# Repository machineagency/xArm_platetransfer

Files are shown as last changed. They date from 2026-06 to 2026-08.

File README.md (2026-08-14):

This is the code repo to use xArm for plate transportation between the Jubilee and a plate shelf.

code

# Setup

1. Create python 3.13 virtual environment

   ```shell
   python3.13 -m venv .venv
   source .venv/bin/activate
   ```
2. install xArm-Python-SDK

   ```shell
   git clone https://github.com/xArm-Developer/xArm-Python-SDK.git
   cd xArm-Python-SDK
   pip install .
   ```

   How to connect to xArm:

   * Turn on the power for the xArm, connect ethernet cable to laptop/Raspberry Pi.
   * It takes few seconds for the xArm to establish internet connection, after the connection box makes three beep sound, run the python code for connecting to xArm.
3. install science jubilee

   ```shell
   git clone https://github.com/machineagency/science-jubilee.git
   cd science-jubilee
   python3 -m pip install -e .
   ```
4. Attach the physical marker on the edge of the print plate.

   3D print a [plate edge marker](./hardware/3D models/plate_edge_marker.stl) and attach to the upper right corner of the print plate. This was used for locating the edge for the print plate.

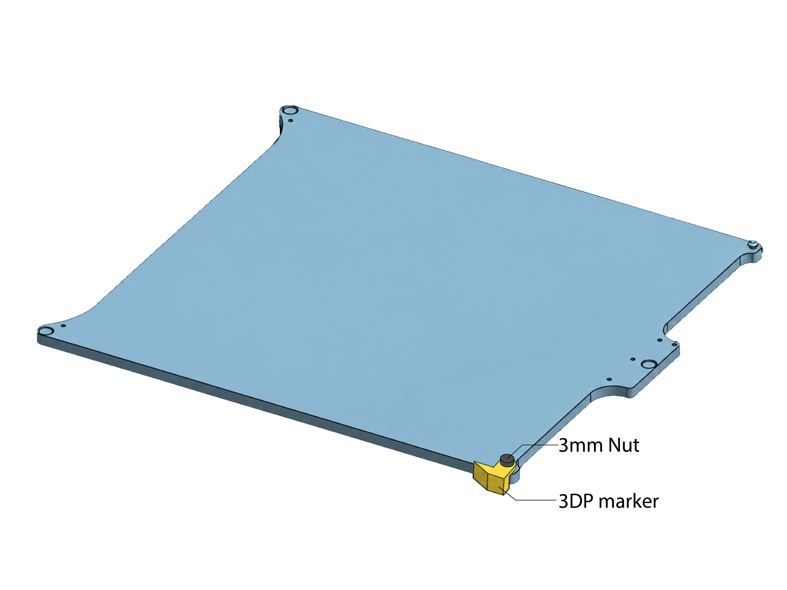
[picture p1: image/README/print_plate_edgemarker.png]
print_plate_edgemarker jig_placement_2
   

# Plate Position Calibration

1. Place the plate on the position you want to register (e.g., shelf/Jubilee), with the 3DP marker on the plate edge closer to the xArm.
2. Run the function `register_position` in `PlateHandler` class.
3. After running the code, manually perform a rough alignment of the xArm to the plate: position the side end stop at the plate’s height and approximately at the midpoint of the plate edge. The holder tool loaded on the xArm should also be approximately parrallel to the plate. Once the rough alignment is complete, press Enter. The xArm will perform automatic calibration process.

# Example Workflow

## Plate transfer & camera capture image

In the camera_workflow_gelinspection.ipynb, we showcased how to use the plate transferring capability with xArm in a webcam capturing workflow. The xArm can pickup different plates on the shelf, put into theJubilee, and use the Jubilee toolhead to pickup a camera tool to capture images of the plate. [Video demo](./video/plate_transfer_cam_workflow.mp4).

example images taken of the different plates:

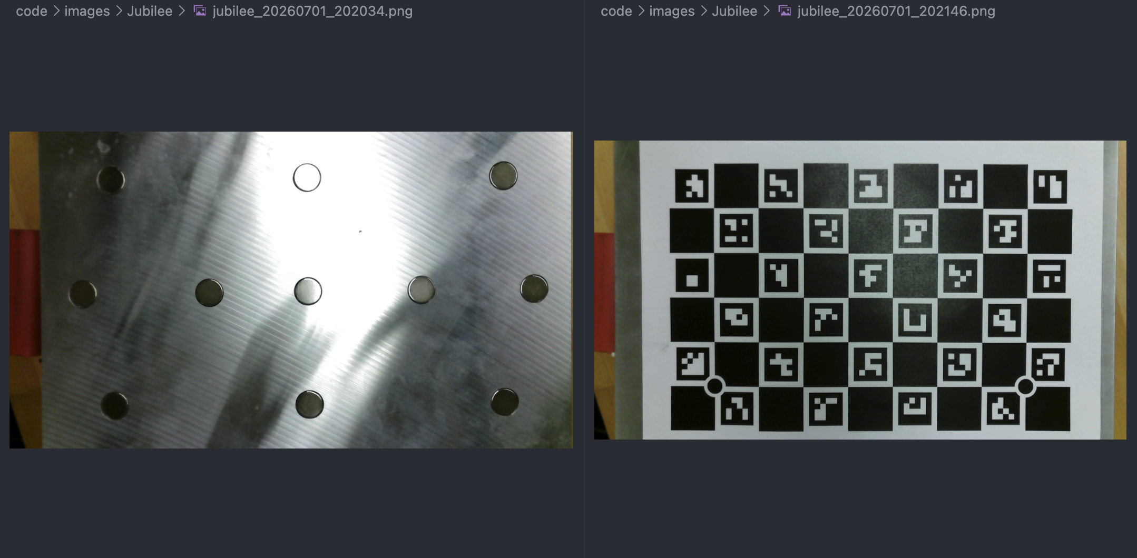
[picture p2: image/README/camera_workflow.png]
camera_workflow


This could also support multi-plate orchestration workflows, where individual plates might require long overall durations but only brief access to the Jubilee. For example, when monitoring hydrogel swelling and deswelling cycles, the Jubilee may only be needed for a few minutes at each stage to capture images or add water/solution, while the swelling or drying process itself takes several hours. During these waiting periods, the plate can be stored on the shelf and automatically loaded onto the Jubilee only when imaging, solution refilling, or other interventions are required.

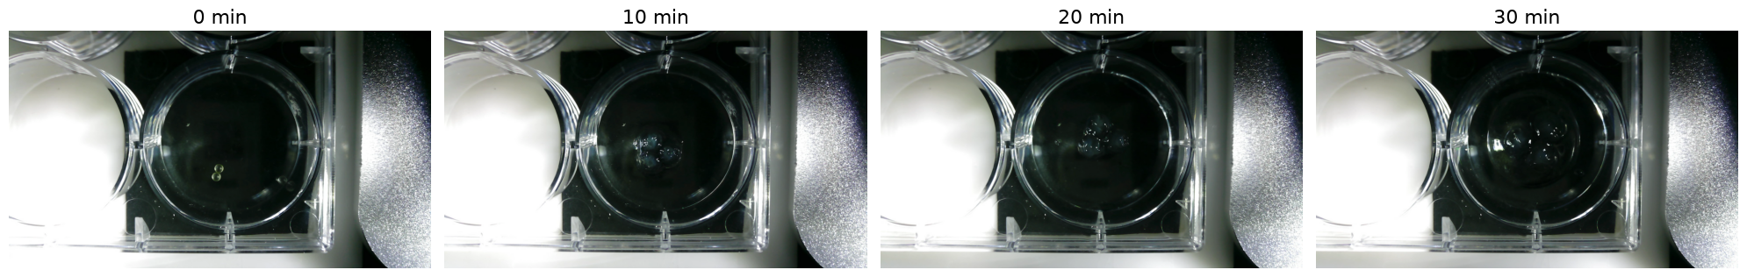
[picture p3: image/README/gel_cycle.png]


# Notes

1. After running the alignment code for the plate at the shelf and Jubilee, the position of the Jubilee and shelf cannot be changed, otherwise needs recalibration.
2. The space between the Jubilee and the shelf should be relatively large to prevent collisions. If the space is too tight, the arm may not be able to move safely or solve a valid path to certain locations.
3. In the Jubilee workflow example, the IP address of the Jubilee was changed to `192.168.2.2` to avoid conflict with xArm address (`192.168.1.205`).

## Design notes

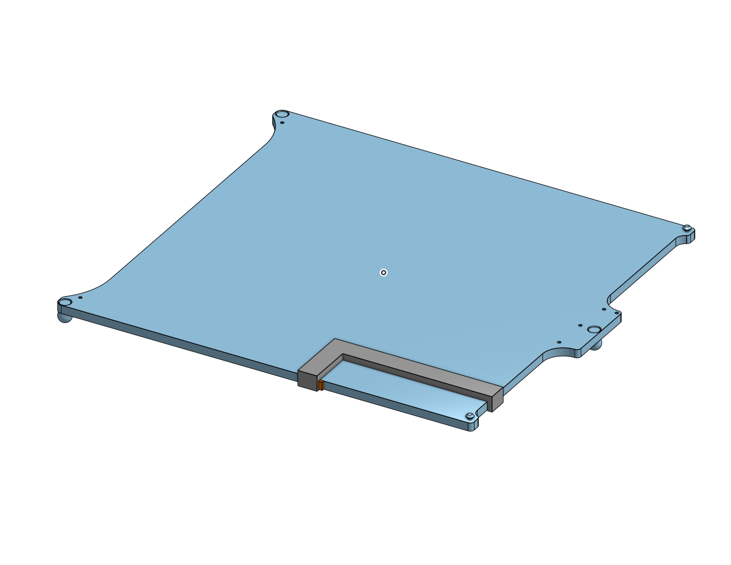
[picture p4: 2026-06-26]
image/README/jig_placement.png

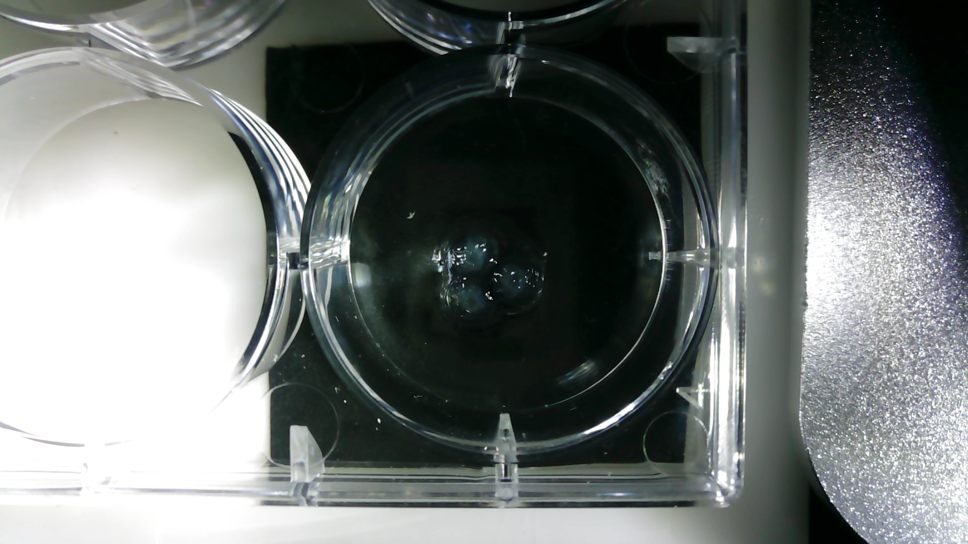
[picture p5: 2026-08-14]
code/images/Jubilee/jubilee_20260813_210422.png

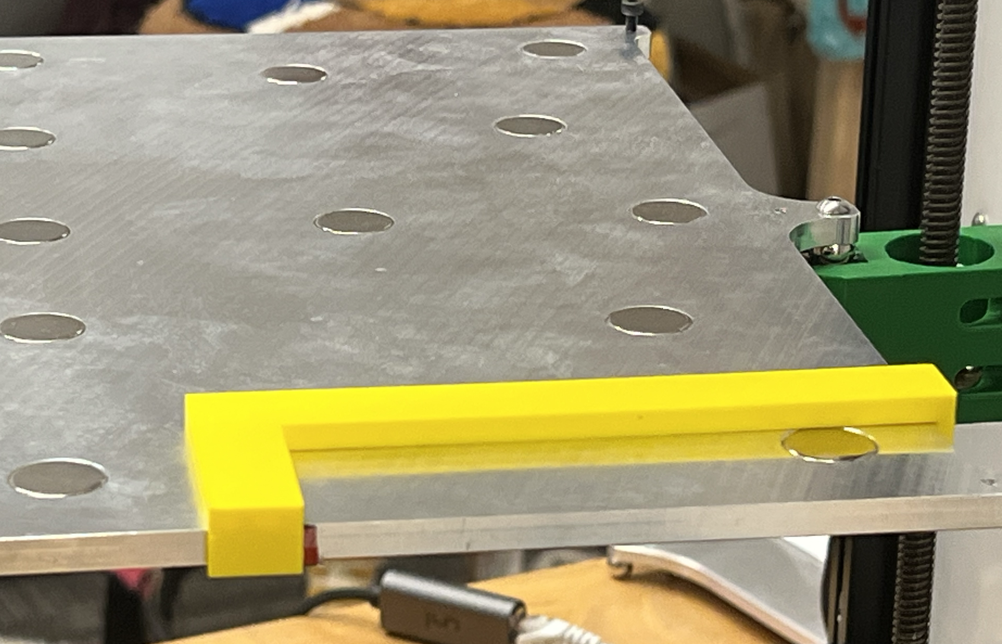
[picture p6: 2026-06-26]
image/README/jig_placement_2.png

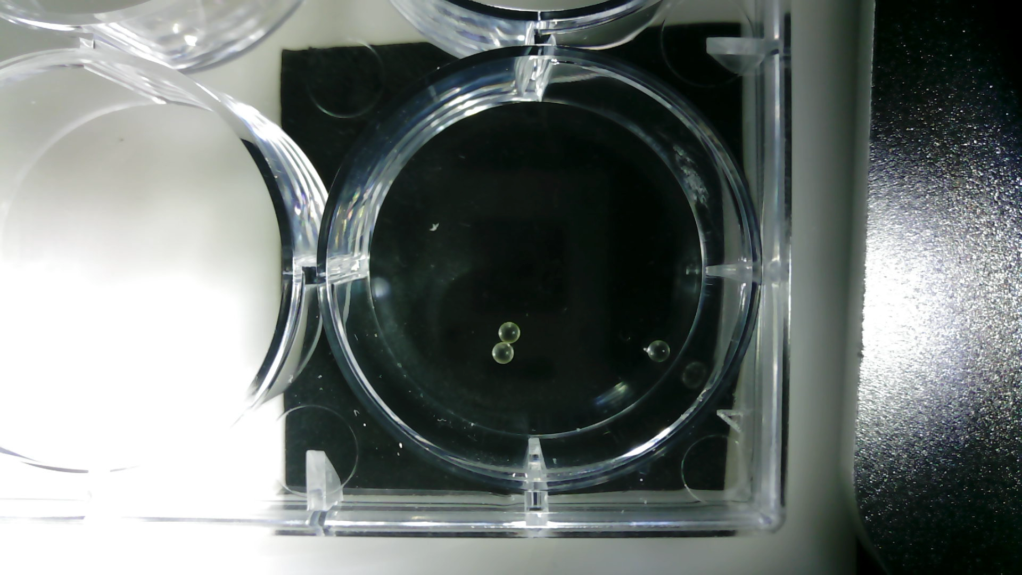
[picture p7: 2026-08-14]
code/images/Jubilee/jubilee_20260813_204859.png

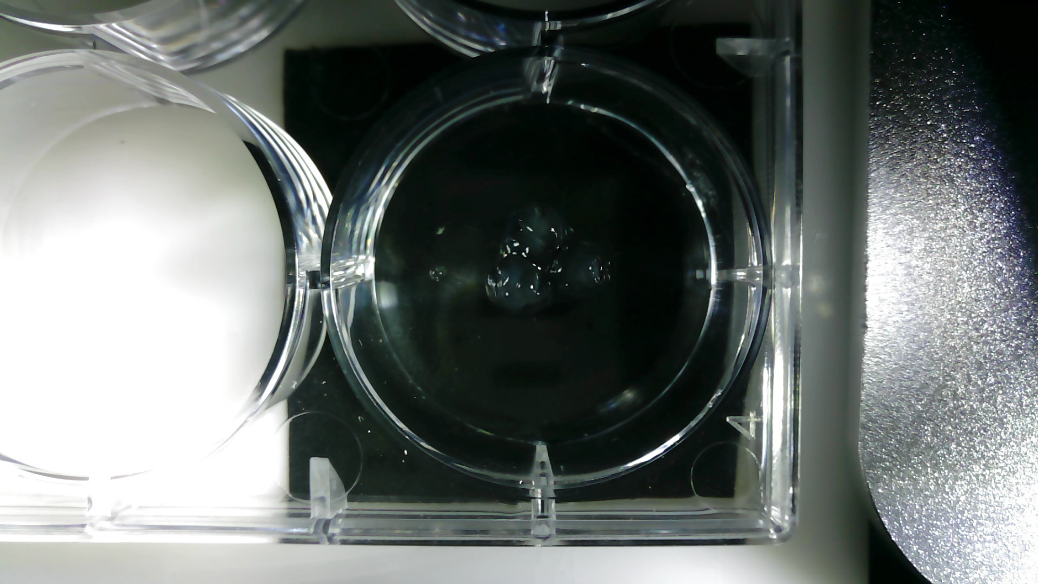
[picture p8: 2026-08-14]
code/images/Jubilee/jubilee_20260813_211548.png

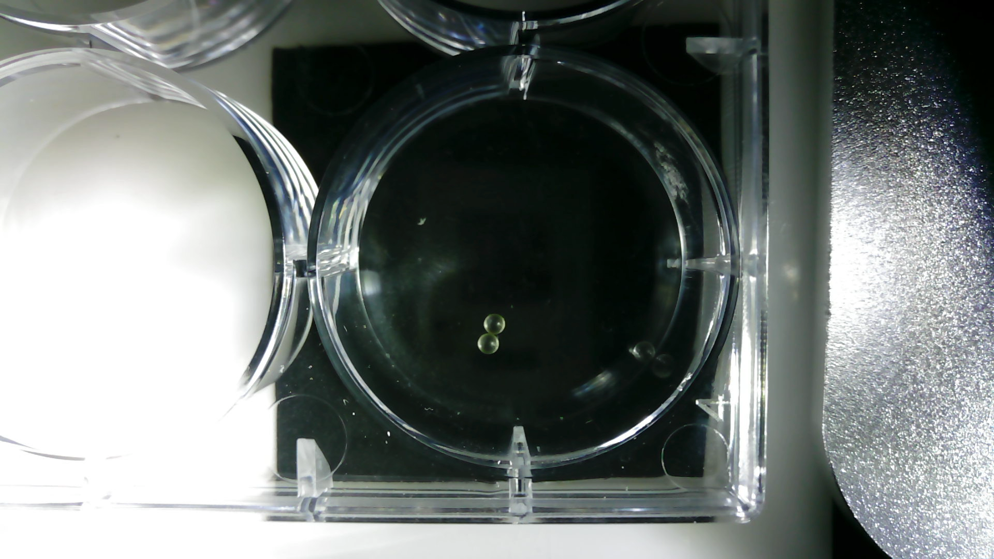
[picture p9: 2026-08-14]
code/images/Jubilee/jubilee_20260813_205239.png

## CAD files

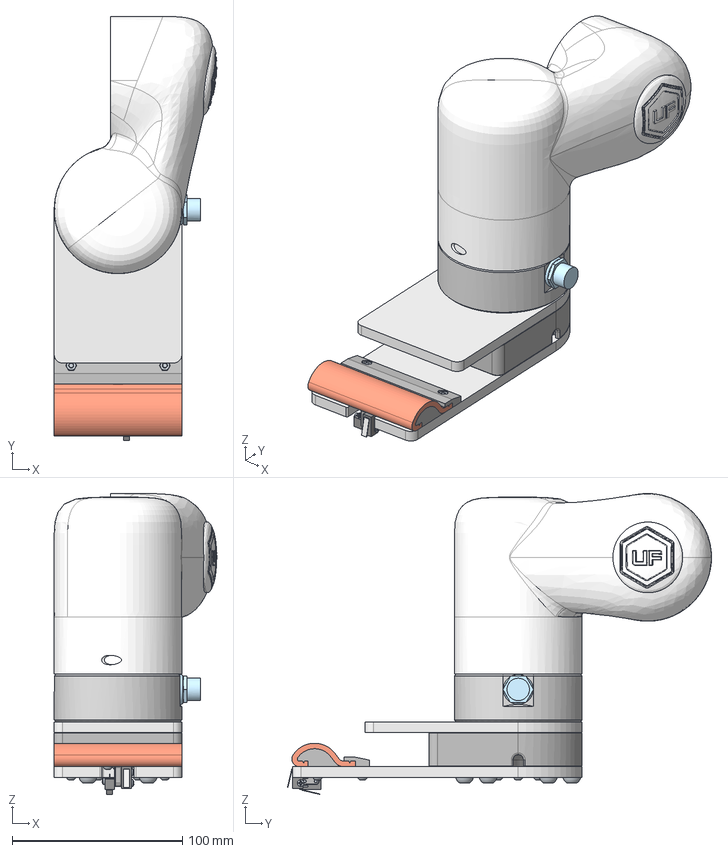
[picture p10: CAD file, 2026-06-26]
hardware/plate move jig/xArm6 Plate Mover/Build Plate Mover Assembly.step
95.5 x 249.0 x 176.7 mm
Socket button head screw M6x1 x 40 x 6
heatset x 10
Socket button head screw M3x0.5 x 10 x 4
Socket button head screw M3x0.5 x 5 x 2
Socket button head screw M3x0.5 x 12 x 8
Top Plate
PH Pan head screw M2x0.40 x 8 x 4
Rubber Pad
Limit Switch x 2
Middle Insert
Tool head x 2
Back Clamp
J6
Hex nut grade A & B M3x0.5 x 2
Front Clamp
Limit Switch Mount
Bottom Plate

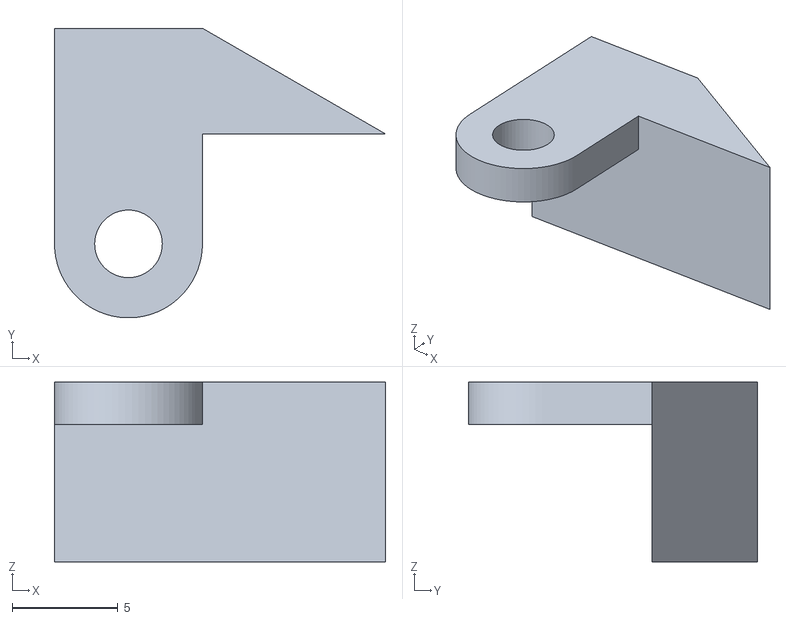
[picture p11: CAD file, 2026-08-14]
hardware/plate marker jig/plate_edge_marker.stl
15.7 x 13.7 x 8.50

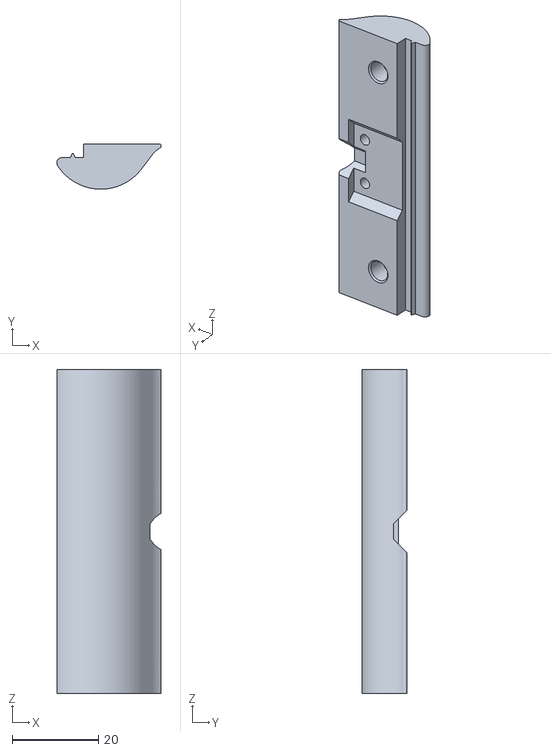
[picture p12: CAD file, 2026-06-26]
hardware/plate move jig/xArm6 Plate Mover/Front Clamp.stl
24.2 x 10.5 x 75.0

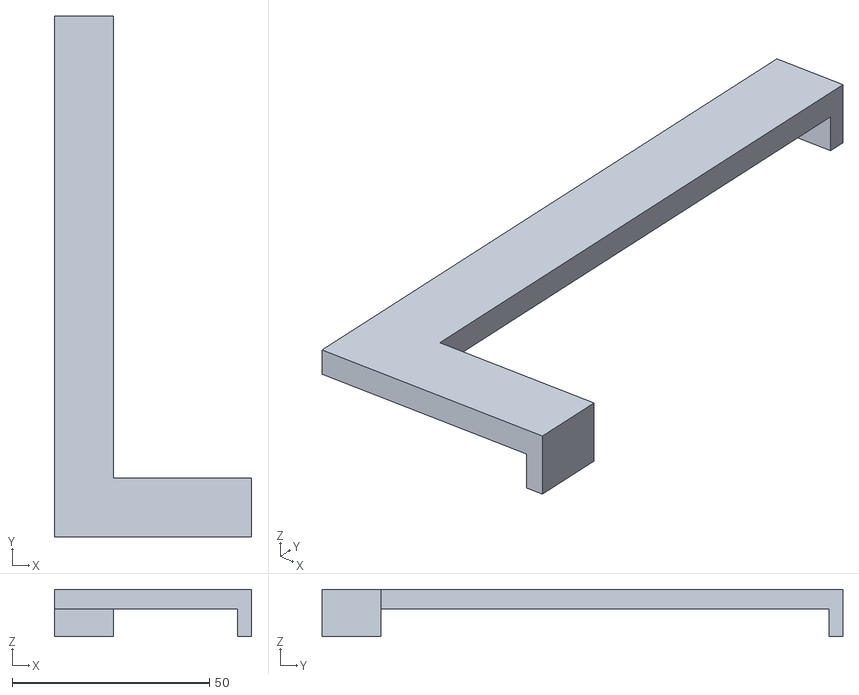
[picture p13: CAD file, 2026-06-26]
hardware/plate marker jig/Jig_for_marker.stl
50.0 x 132.1 x 12.0

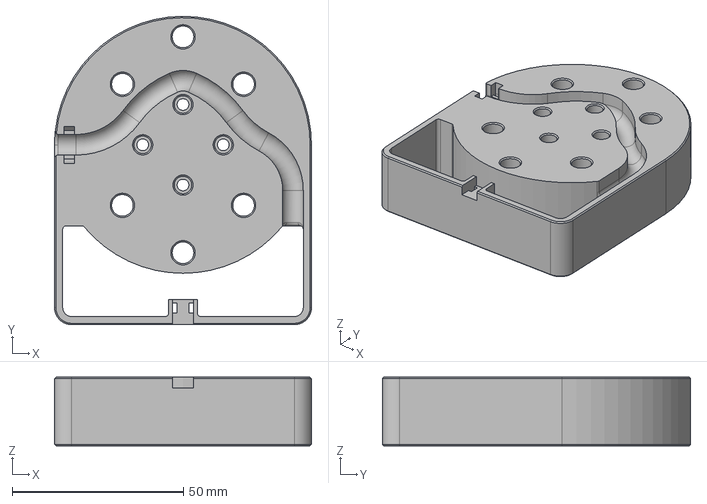
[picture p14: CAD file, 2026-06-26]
hardware/plate move jig/xArm6 Plate Mover/Middle Insert.step
75.0 x 90.0 x 20.0 mm

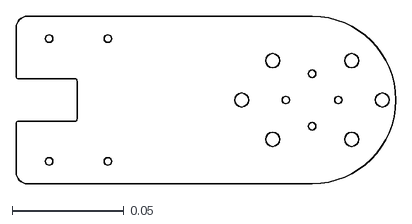
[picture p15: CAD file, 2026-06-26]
hardware/plate move jig/xArm6 Plate Mover/Bottom Plate.dxf
0.17 x 0.075

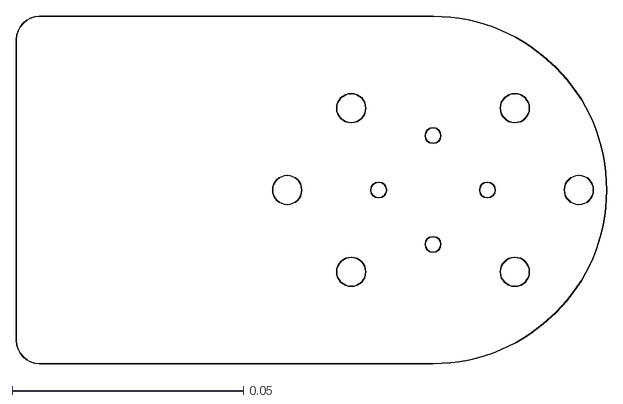
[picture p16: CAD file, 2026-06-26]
hardware/plate move jig/xArm6 Plate Mover/Top Plate.dxf
0.128 x 0.075

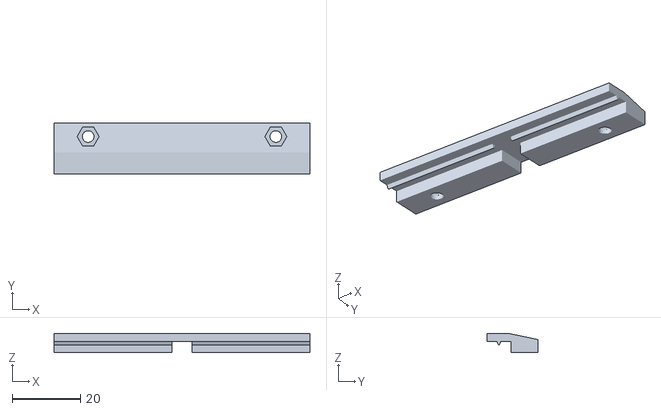
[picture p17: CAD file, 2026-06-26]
hardware/plate move jig/xArm6 Plate Mover/Back Clamp.stl
75.0 x 15.0 x 5.60

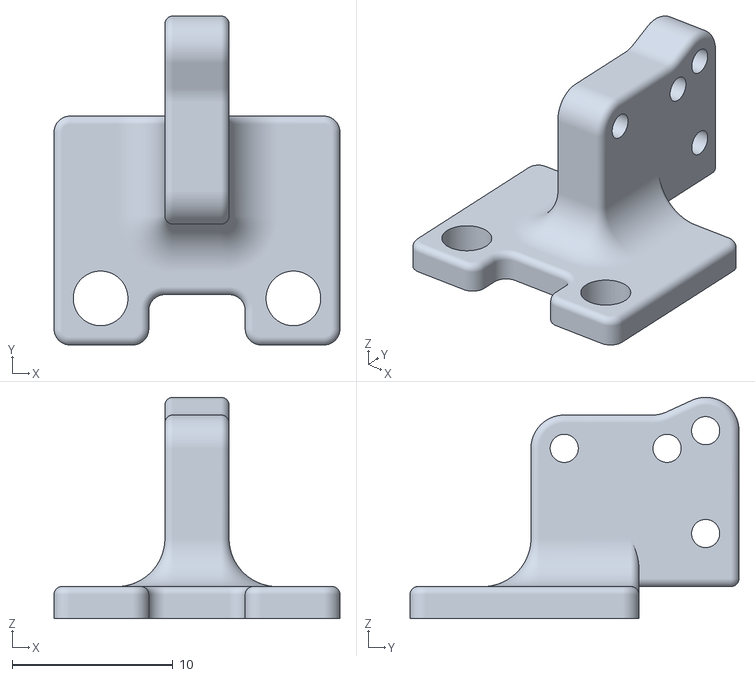
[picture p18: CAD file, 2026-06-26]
hardware/plate move jig/xArm6 Plate Mover/Limit Switch Mount.stl
17.8 x 20.5 x 13.8

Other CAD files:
hardware/plate move jig/xArm6 Plate Mover/Middle Insert.stl

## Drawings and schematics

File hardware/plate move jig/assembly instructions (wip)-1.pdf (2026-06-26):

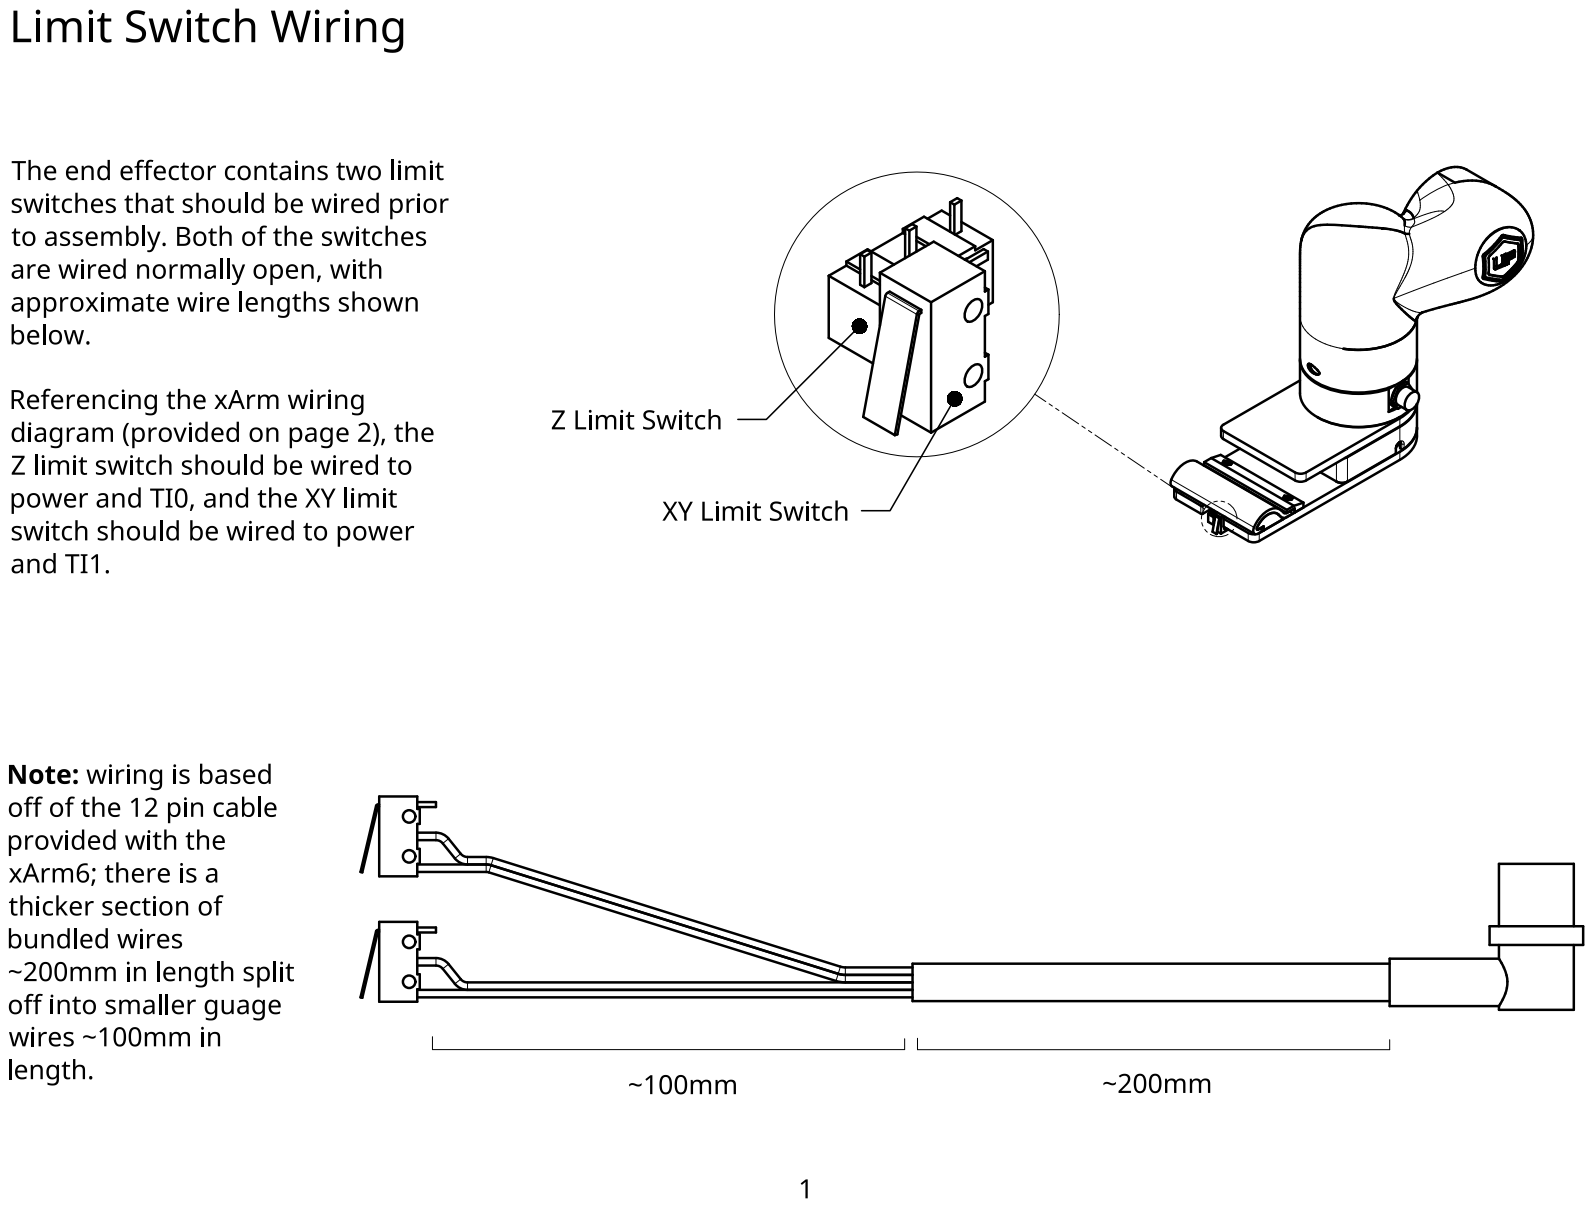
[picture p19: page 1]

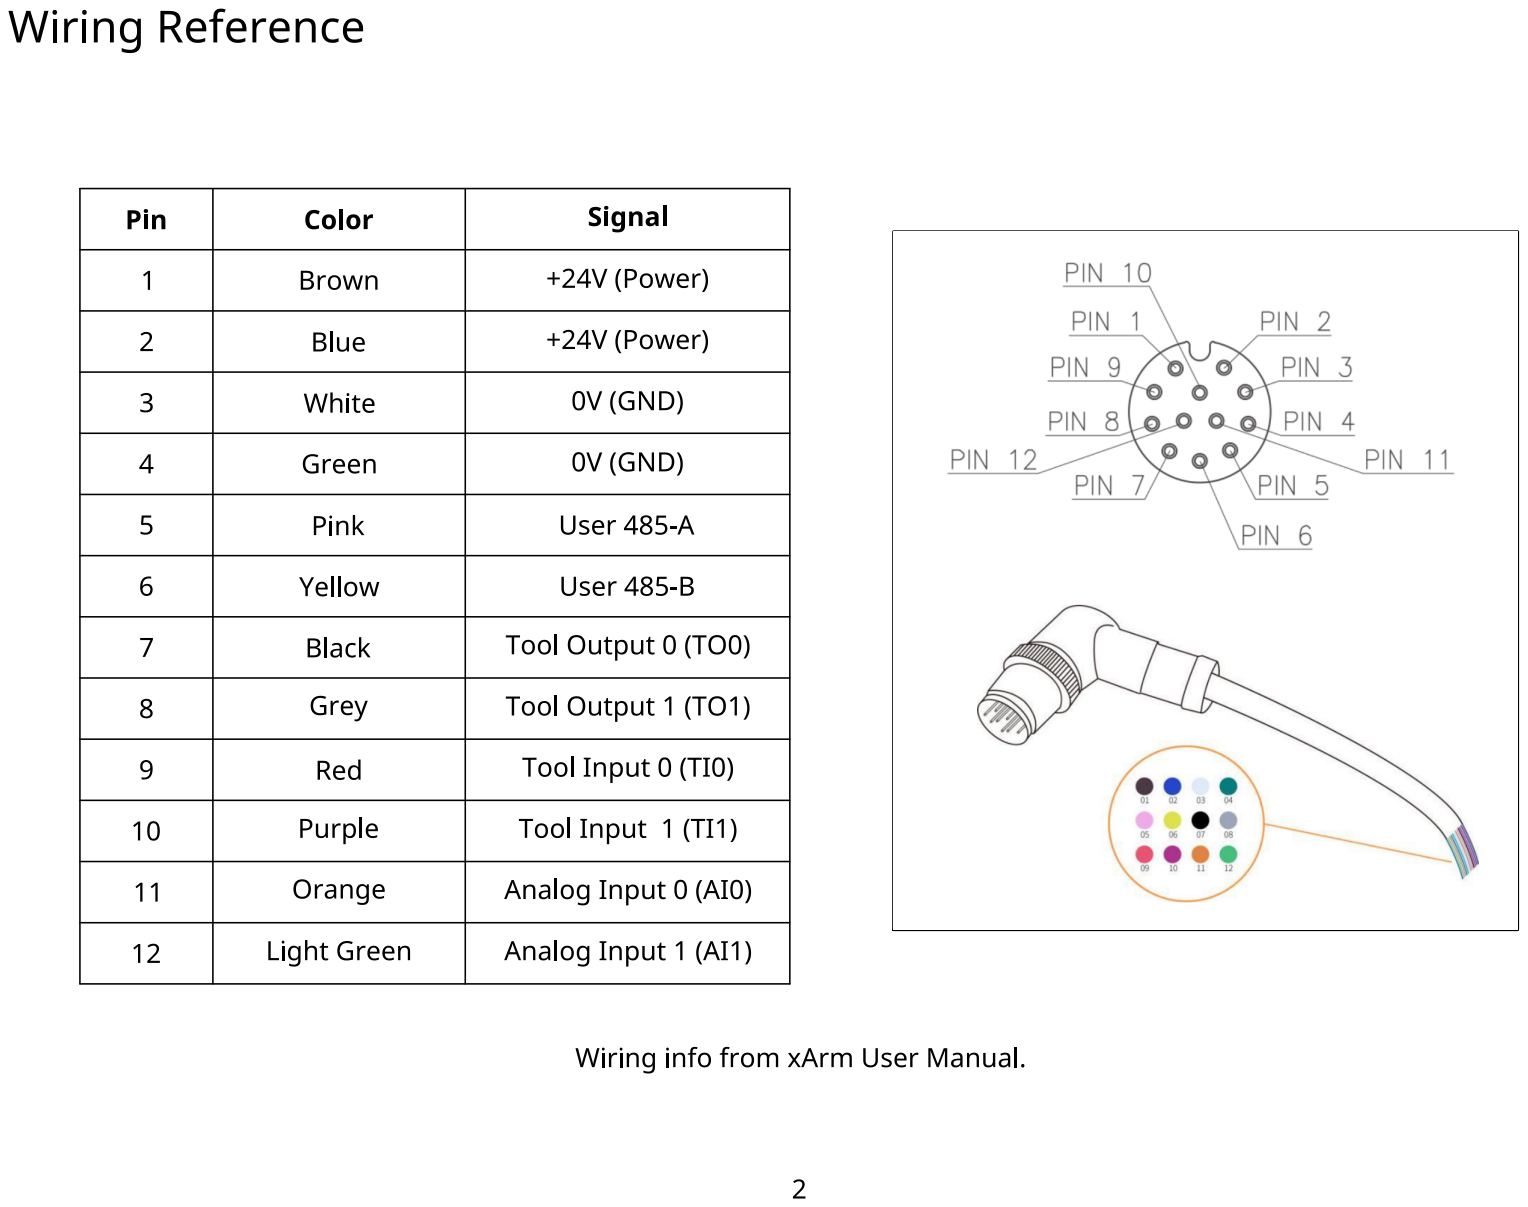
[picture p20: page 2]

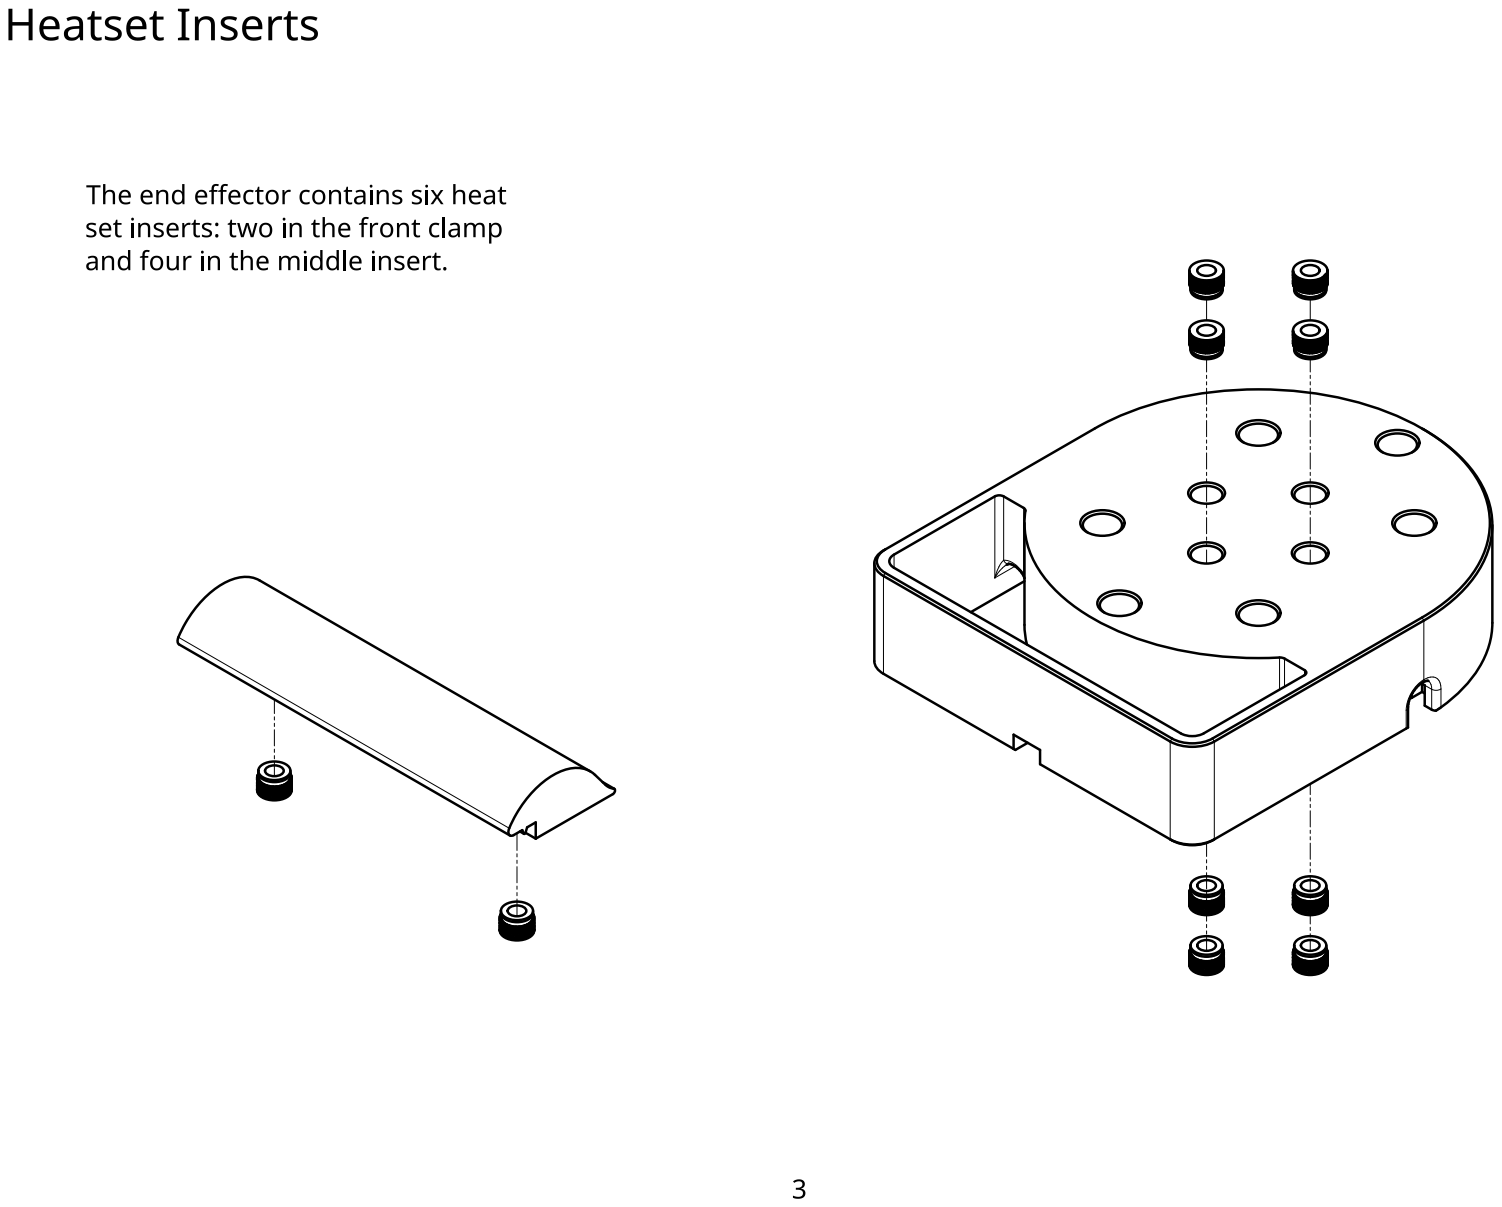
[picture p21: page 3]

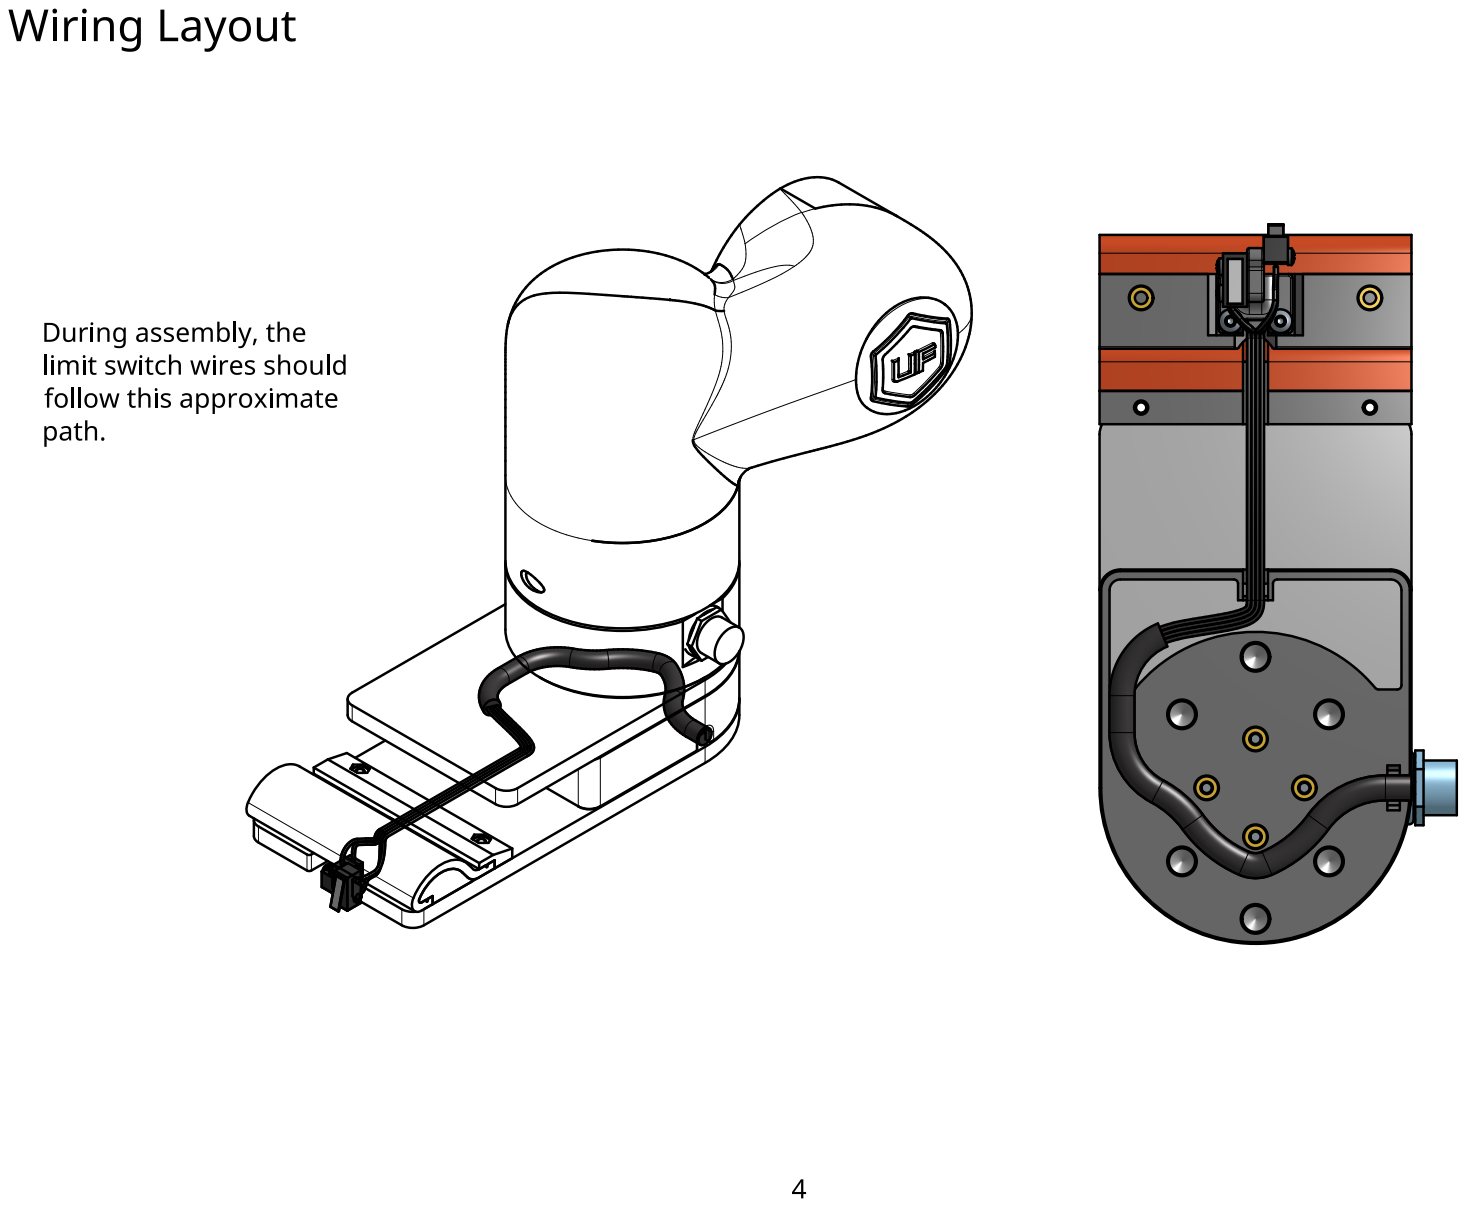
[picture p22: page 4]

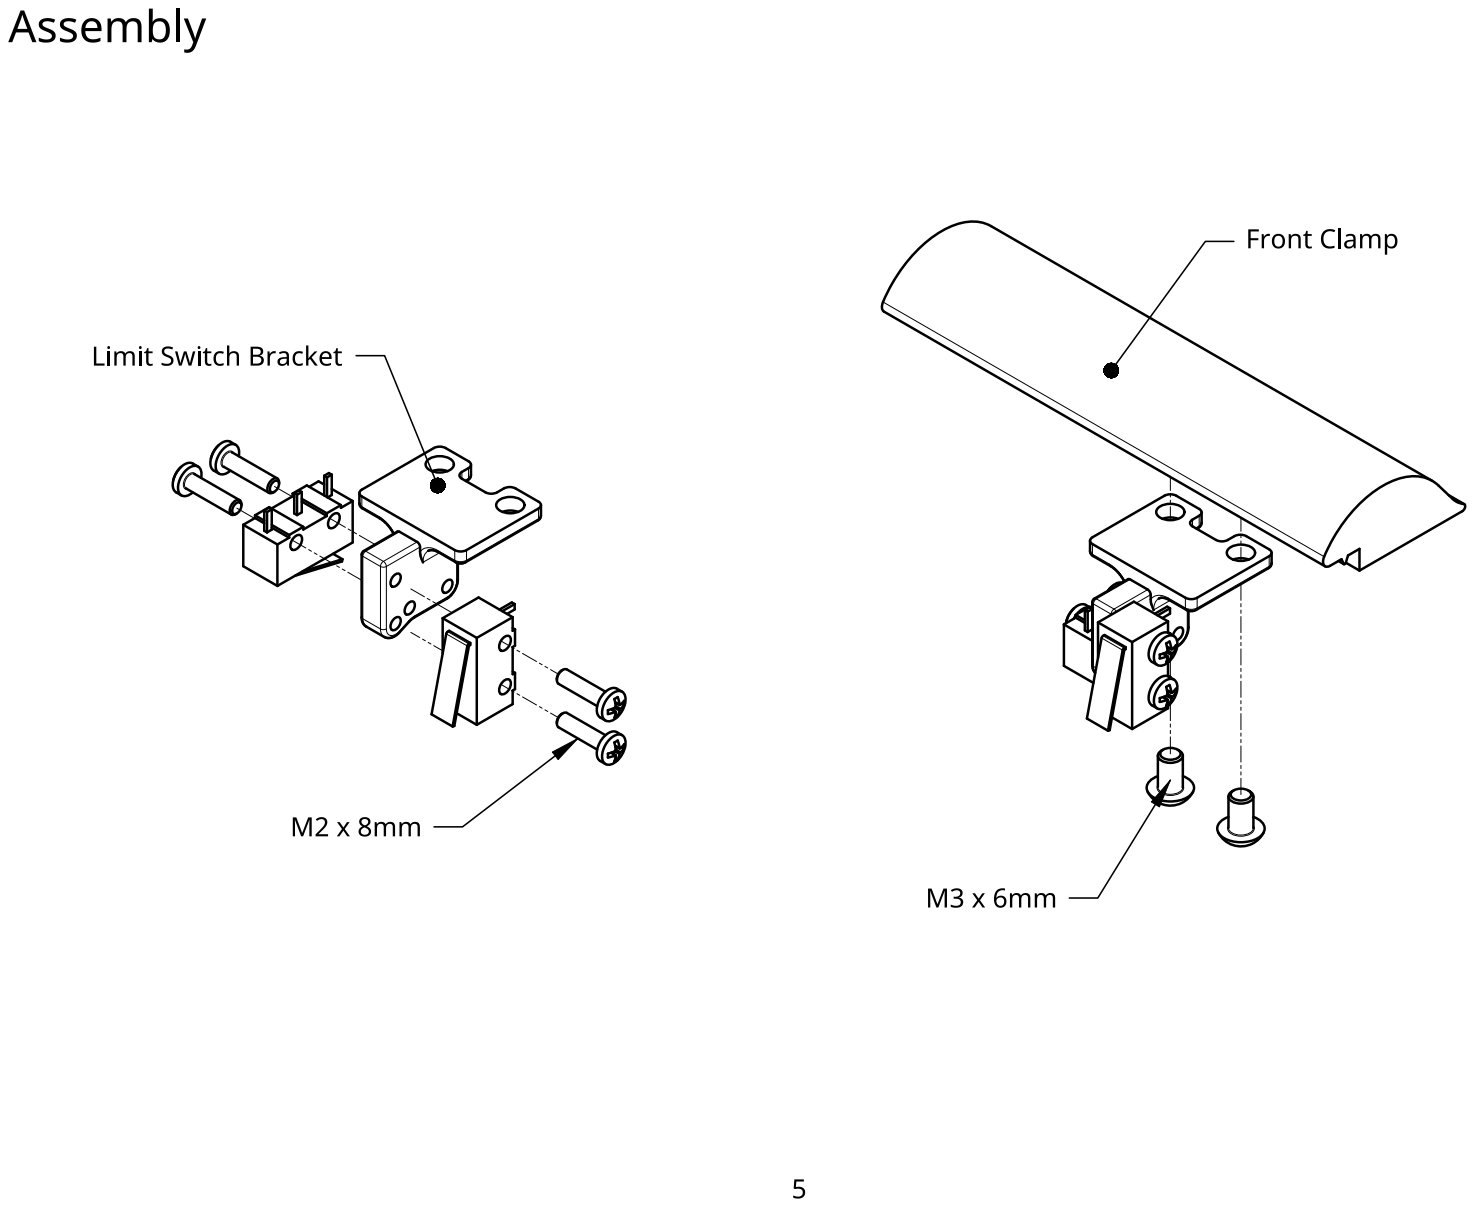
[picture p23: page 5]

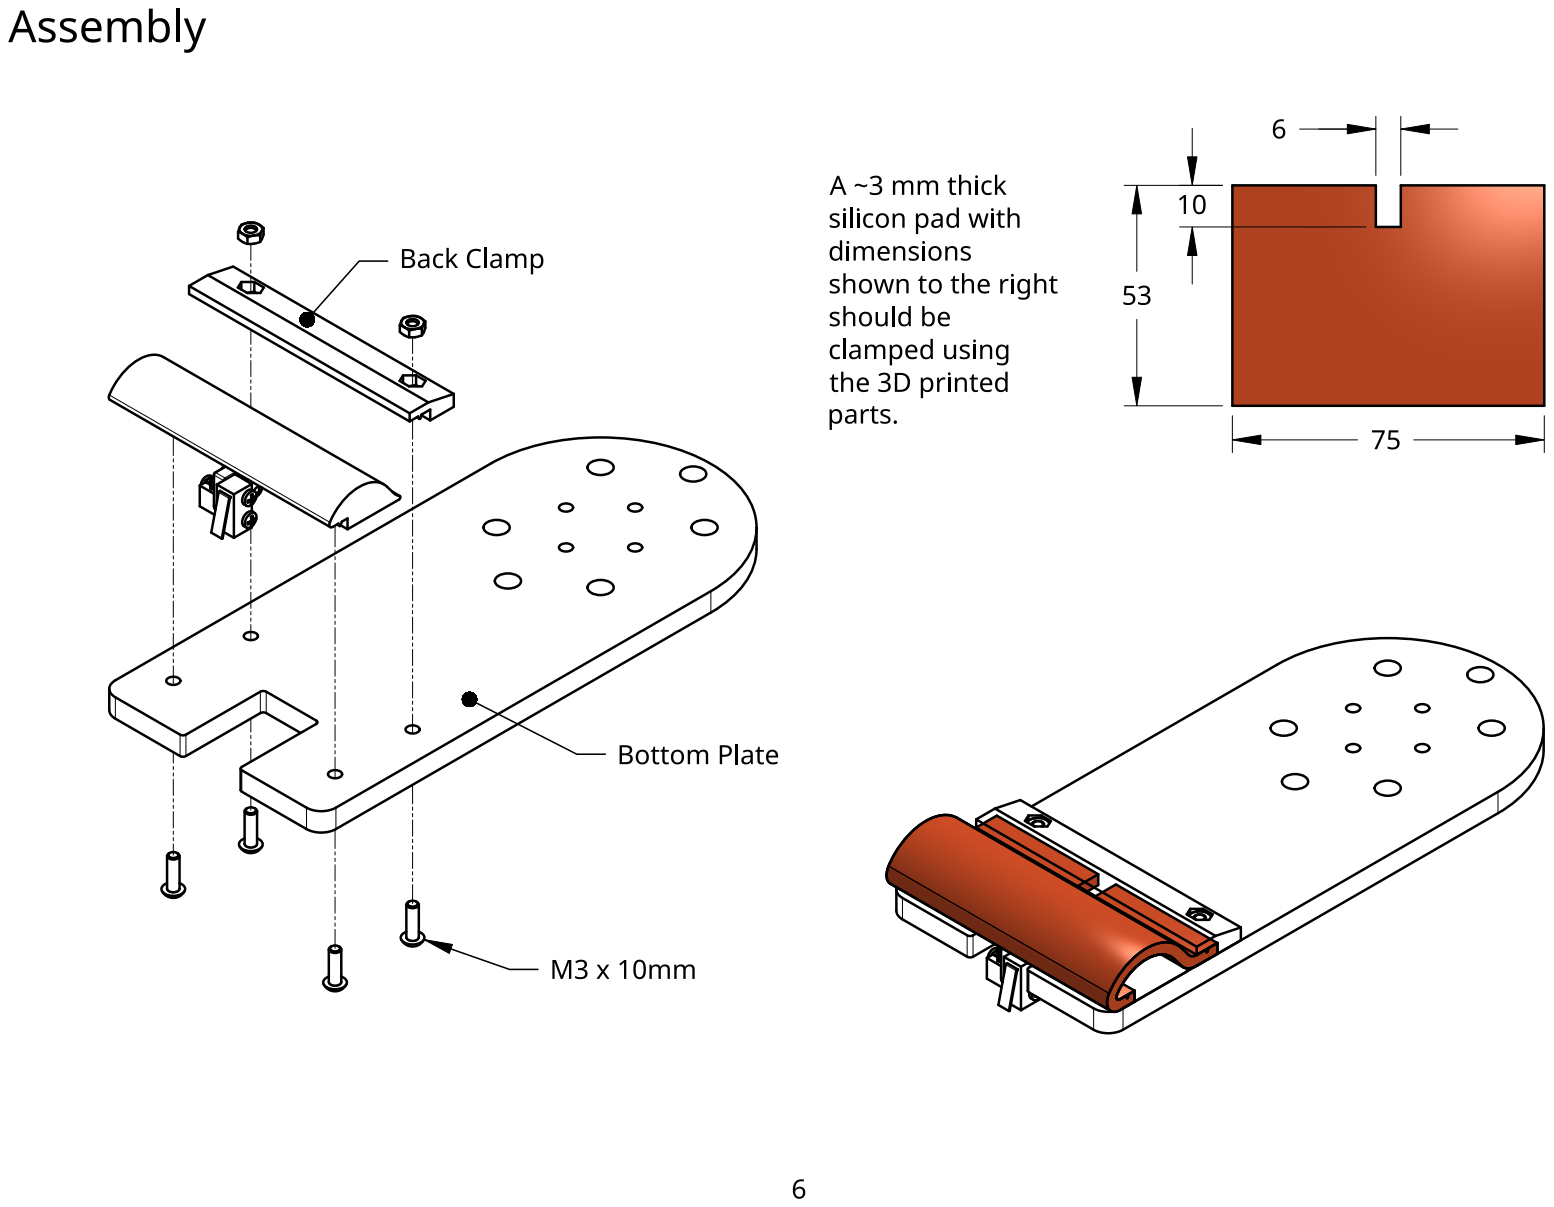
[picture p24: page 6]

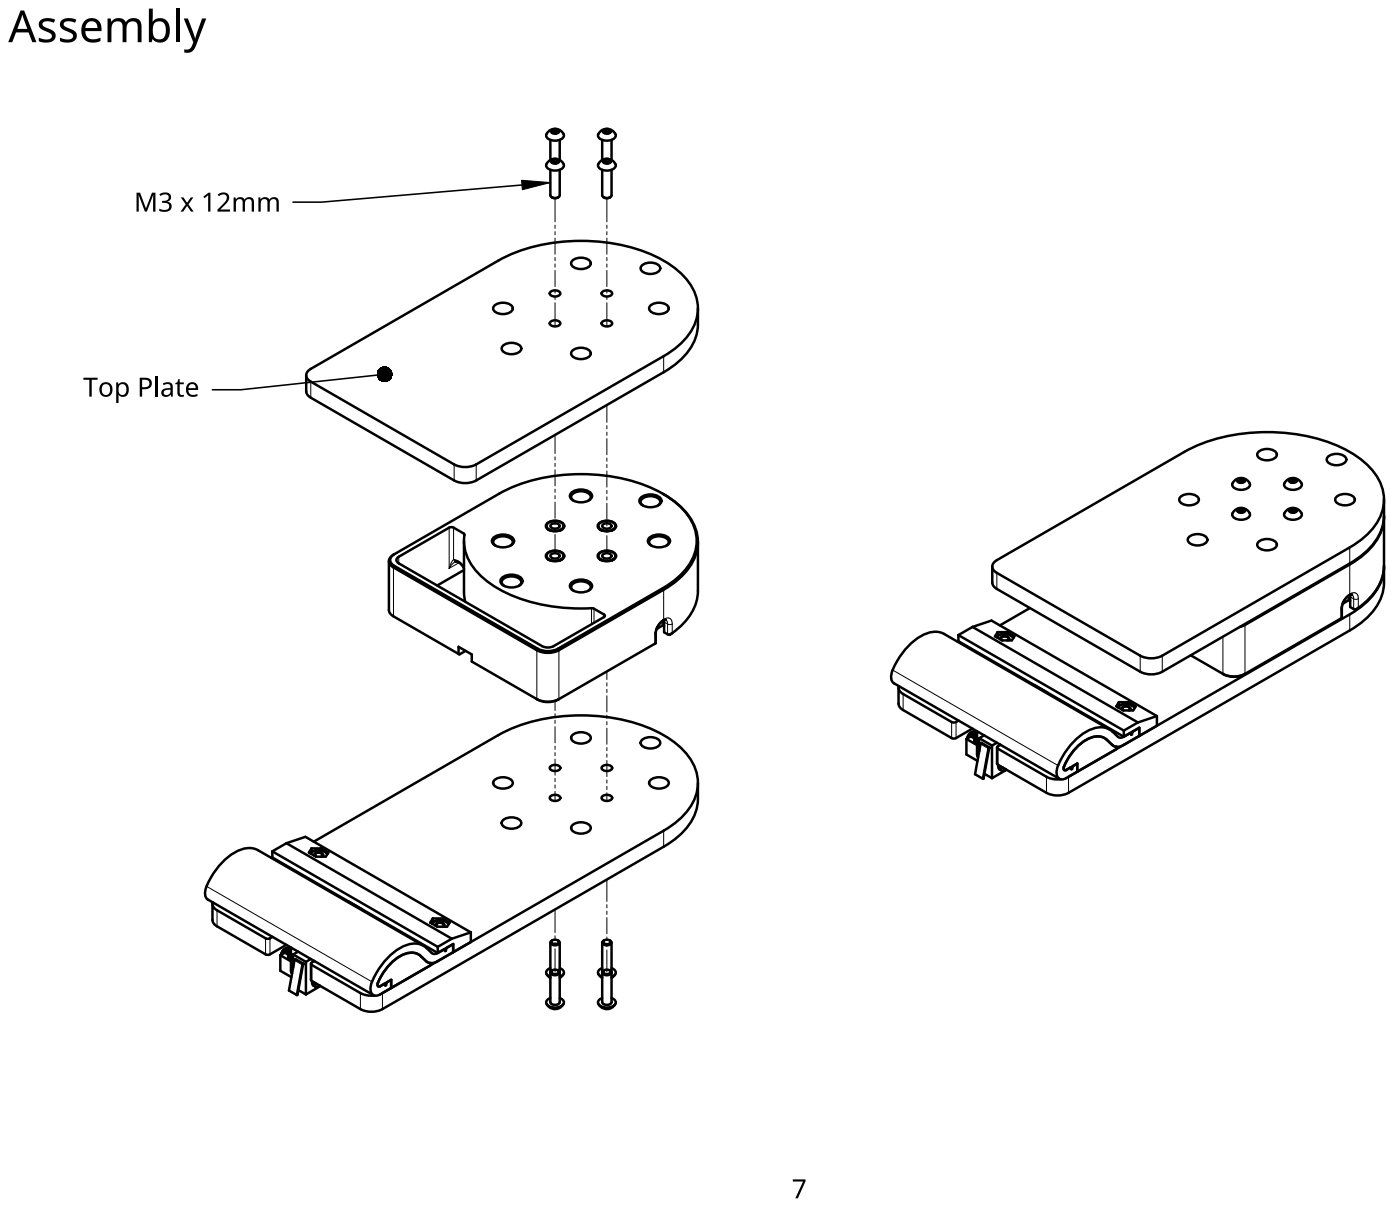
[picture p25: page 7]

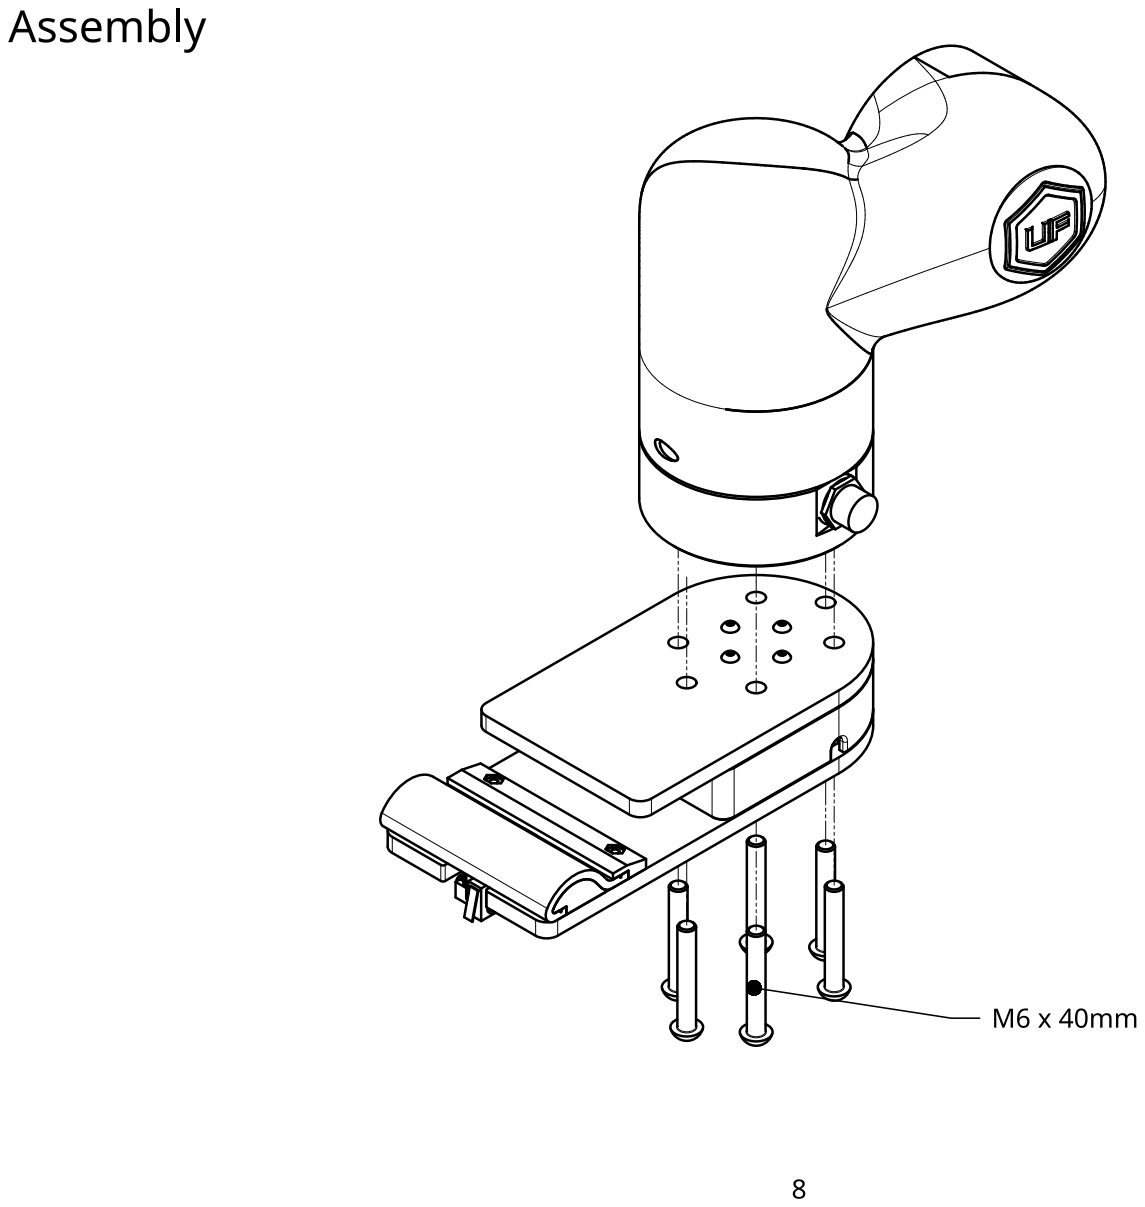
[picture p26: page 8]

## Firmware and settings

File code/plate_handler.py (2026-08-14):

# todos: add store and read registerd position from file


from __future__ import annotations

import json
from pathlib import Path
from typing import Any, Optional

import numpy as np


class PlateHandler:
    """
    Control an xArm-based build-plate transfer system.

    The class stores every calibrated position and its current plate occupancy
    in one dictionary named ``plate_positions``. Each entry has this form::

        {
            "position_id": "Jubilee",
            "pose": np.array([x, y, z, roll, pitch, yaw]),
            "loaded_plate": "plate_1",  # or None
        }
    """

    def __init__(
        self,
        arm: Any,
        *,
        default_move_speed: float = 100,
        probing_speed: float = 5,
        probing_step: float = 0.5,
    ) -> None:
        """
        Create a PlateHandler around an existing xArm API object.

        Parameters
        ----------
        arm:
            Existing xArm API object created outside this class.
        default_move_speed:
            Default speed in mm/s for plate-transfer movements.
        probing_speed:
            Slow speed used during contact probing.
        probing_step:
            Incremental probe distance in millimeters.

        Notes
        -----
        The constructor does not move the robot. Call ``initialize()`` before
        calibration or plate-transfer operations.
        """
        if arm is None:
            raise ValueError("arm must be an initialized xArm API object.")
        if default_move_speed <= 0:
            raise ValueError("default_move_speed must be greater than zero.")
        if probing_speed <= 0:
            raise ValueError("probing_speed must be greater than zero.")
        if probing_step <= 0:
            raise ValueError("probing_step must be greater than zero.")

        self.arm = arm
        self.default_move_speed = float(default_move_speed)
        self.probing_speed = float(probing_speed)
        self.probing_step = float(probing_step)

        # positions and plate occupancy.
        self.plate_positions: dict[str, dict[str, Any]] = {}
        self._initialized = False

    # ------------------------------------------------------------------
    # Public setup and registry methods
    # ------------------------------------------------------------------

    def initialize(self) -> None:
        """
        Apply the same xArm configuration used in the original notebook.

        The method clears warnings/errors, enables motion, sets the world and
        TCP offsets, configures the unloaded tool payload, and returns the xArm
        to normal position-control mode. It does not home or reposition the arm.
        """
        self.arm.clean_warn()
        self.arm.clean_error()
        self.arm.motion_enable(enable=True)
        self.arm.set_world_offset([0, 0, 8, 0, 0, 0])
        self.arm.set_tcp_offset([119.569, 0, 12.6, 0, 0, -1])
        self.arm.set_state(state=0)
        self.arm.set_tcp_load(
            weight=0.4997 + 0.048,
            center_of_gravity=[41, 0, 18],
        )
        self.arm.set_mode(0)
        self.arm.set_state(state=0)
        self._initialized = True

    def register_position(
        self,
        position_id: str,
        *,
        overwrite: bool = False,
        save_to_file: bool = False,
        position_file_path: str = "./position.json",
    ) -> dict[str, Any]:
        """
        Rough-align manually, fine-align automatically, and register a position.

        1. Enter teach mode for manual rough alignment.
        2. Ask the user to align the tool corner with the position marker.
        3. Return to position-control mode.
        4. Automatically level roll/pitch using three Z probes.
        5. Automatically correct yaw using two edge probes.
        6. Search along Y for the raised reference point or edge feature.
        7. Move to the final safe reference pose.
        8. Save the calibrated pose in ``self.plate_positions``.

        Parameters
        ----------
        position_id:
            Unique position name such as ``"Jubilee"`` or ``"Shelf_1"``.
        overwrite:
            If False, an existing position cannot be recalibrated. If True, the
            pose is replaced while preserving its current ``loaded_plate``.
        save_to_file:
            If True, add or update this position in ``position_file_path`` after
            calibration.
        position_file_path:
            JSON file used when ``save_to_file`` is True. The file is created if
            it does not already exist.

        Returns
        -------
        dict
            The registered position dictionary containing ``position_id``,
            ``pose``, and ``loaded_plate``.

        Warning
        -------
        This method physically moves the robot. Keep the workspace clear and
        keep the emergency stop accessible.
        """
        self._require_initialized()
        self._validate_identifier(position_id, "position_id")

        if position_id in self.plate_positions and not overwrite:
            raise ValueError(
                f"Position '{position_id}' is already registered. "
                "Use overwrite=True to recalibrate it."
            )

        loaded_plate = None
        if position_id in self.plate_positions:
            loaded_plate = self.plate_positions[position_id]["loaded_plate"]

        self.arm.set_mode(2)
        self.arm.set_state(0)
        self.arm.start_record_trajectory()
        input(
            f"Manually align the tool corner with the marker for "
            f"'{position_id}', then press Enter."
        )
        self.arm.stop_record_trajectory()
        self.arm.set_mode(0)
        self.arm.set_state(0)

        # rough-to-fine alignment sequence
        self.arm.set_tool_position(x=-20, speed=50, wait=True)
        self.arm.set_tool_position(z=-30, speed=50, wait=True)
        self.arm.set_tool_position(x=60, speed=50, wait=True)
        self._level_position()
        self.arm.set_tool_position(x=-60, speed=50, wait=True)
        self.arm.set_tool_position(z=17, speed=50, wait=True)
        self._align_yaw()
        self._find_plate_edge()
        self.arm.set_tool_position(z=30, speed=50, wait=True)

        plate_position = {
            "position_id": position_id,
            "pose": self._get_current_pose(),
            "loaded_plate": loaded_plate,
        }
        self.plate_positions[position_id] = plate_position
        if save_to_file:
            self.save_position(position_id, position_file_path)
        return plate_position

    def save_position(
        self,
        position_id: str,
        position_file_path: str = "./position.json",
    ) -> Path:
        """
        Add or update one registered position in a JSON file.
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

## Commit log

2026-06-26 added plate move jig files
    [Back Clamp.stl, Bottom Plate.dxf, Build Plate Mover Assembly.step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]
2026-07-06 camera workflow
2026-08-14 camera workflow gel inspection
    [plate_edge_marker.stl]
